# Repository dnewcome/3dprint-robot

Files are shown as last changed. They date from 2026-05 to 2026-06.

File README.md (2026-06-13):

# 3D-Printed Cycloidal Robot Arm

A 3D-printable cycloidal robot arm, designed for **low backlash**, **commodity
parts** (NEMA17, 608 bearings, magnets), and **fast iteration** on a home
printer. Two design tracks live here:

- **Integrated-actuator arm (current direction).** A **5-DOF** arm built from
  printed **sections** that fuse directly to off-the-shelf
  [Sweep Dynamics](https://www.sweepdynamics.com) **20:1 Micro Cycloidal**
  drives (a larger cycloidal at the base slew). Each section integrates one
  half of a joint at each end — the rotating cyclo **body** (upstream joint
  output) on one end, the **NEMA17 motor plate** (downstream motor mount) on
  the other — so the link *is* the actuator mount. See `arm_section.scad`.
- **From-scratch parametric joint (original track).** A **3-DOF** positioning
  trunk built around **one parametric cycloidal joint** (`cycloid_joint.scad`)
  used three times — no bought actuators. Kept as the ground-up alternative.

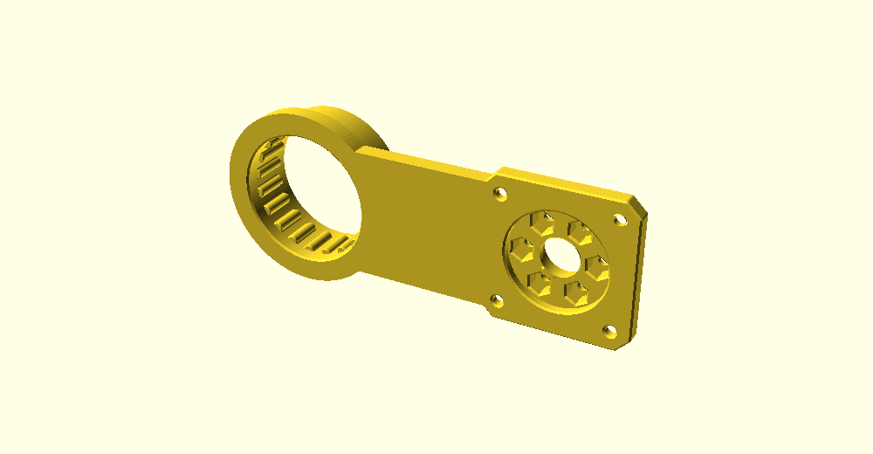
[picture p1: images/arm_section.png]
integrated arm section


**Full design rationale → [DESIGN.md](DESIGN.md).** This README is the map.

## Status
Active. **Current focus:** the integrated-actuator arm — the long arm section
is modeled and prints as one fused solid; the two 90° end sections (base→slew,
wrist→tool-roll) are next. No part is finalized for print yet.
**Toolchain:** the CAD is **[build123d](https://build123d.readthedocs.io)**
(Python + OCC) — it imports the vendor STEP files as exact solids, a better fit
for the fused-actuator parts than mesh import. The old OpenSCAD `.scad` sources
are **deprecated** and archived in [`legacy/`](legacy/README.md).

## Headline specs
| | |
|---|---|
| Near-term DOF | **3** (positioning trunk: J1 yaw + J2 shoulder + J3 elbow) |
| Future DOF | 5–6 via parked wrist / BLDC upgrades |
| Payload | 250 g |
| Reach | ~480 mm from shoulder |
| Print volume target | 250 mm cube |
| Joint drive | NEMA17 → 2:1 GT2 belt → cycloid (18:1) = **36:1** |
| Output bearing | large BB crossed-roller, **outboard of the gears** (J1's = the moment bearing) |
| Feedback | output-side absolute magnetic encoder per joint |

## Key decisions (the short version)
- **One cycloidal joint, three sizes** — build/tune once, reprint to scale.
- **Floating-roller cycloid** — nylon rollers, clearance sets backlash, SLA
  bearing surfaces for finish. No steel dowels required.
- **Bearing outboard of the gearset** (clevis-free stator/rotor cartridge) →
  carries the cantilever moment; **J1 = same cartridge vertical**, bearing sized up.
- **3 DOF is useful** — three joints position the tool point; bolt on a fixed
  gripper or manual wrist. Extra DOF is a deliberate later step, not v1.
- **Explorations parked, not deleted** — cable drive, wrist, BLDC, harmonic
  all live in [`parked/`](parked/) for when the trunk proves out.

## Repo map
**Build path (root)**
- `arm_section.py` — **the integrated-actuator links** (build123d, current
  direction). `python arm_section.py upper` fuses the Sweep micro-cyclo body +
  NEMA17 plate (exact STEP solids) into one printable section → `out/`.
- `arm_assembly.py` — **the assembled robot, the single source of truth.**
  Defines the kinematic chain once, derives joint frames from the part geometry,
  and generates the sim model (`sim/arm_trunk.urdf`), the meshes, and a CAD
  preview. Change a section length / motor here and it flows everywhere.
- `extract_vendor_steps.py` — pulls the two parts out of your purchased
  assembly STEP (run once before `arm_section.py` / `arm_assembly.py`).
- `vendor/` — the two Sweep Dynamics input parts + how to get the rest
  ([`vendor/README.md`](vendor/README.md)). Paid geometry — read [`NOTICE`](NOTICE).
- `encoder_joint_spec.md` — integrated output-side encoder.
- `DESIGN.md` — source of truth.
- [`CAD_NOTES.md`](CAD_NOTES.md) — build123d/OCP workflow + OCC gotchas
  (live preview, `make watch`, coincident-cut hangs, null-triangulation healing).
- [`LAB_NOTEBOOK.md`](LAB_NOTEBOOK.md) — running log of process variables
  (filament, color, print orientation, fits) + measured hardware anchors.
- [`legacy/`](legacy/README.md) — **deprecated** OpenSCAD `.scad` sources
  (`arm_section`, plus the from-scratch `cycloid_joint`/`arm_trunk` 3-DOF track).

**Simulation & analysis** → [`sim/`](sim/README.md) — MuJoCo model + tools to
pose it, size the motors (torque/reach/motor-catalog), budget backlash, watch it
hold/sag under gravity, and run a closed-loop reach controller (the digital-twin
foundation). Where the motor/reduction/backlash trade-offs were quantified.

**Parked explorations** → [`parked/`](parked/README.md) — cable/capstan drive,
wrist mechanisms, harmonic ring, BLDC motor options + integrated actuator,
and the now-merged joint-source files.

## Building the CAD
[build123d](https://build123d.readthedocs.io) (`pip install build123d`):
```bash
python extract_vendor_steps.py          # once: pull the 2 parts from your STEP
python arm_section.py upper             # -> out/upper.stl + out/upper.step
```
> Needs the **vendor geometry you purchase** from Sweep Dynamics (the assembly
> STEP) — see [`vendor/README.md`](vendor/README.md) and [`NOTICE`](NOTICE).
> Deprecated OpenSCAD versions render with `openscad` from [`legacy/`](legacy/README.md).

## Prototype plan
1. **One joint (J2)** — print the disc, pin ring, cam, flange + BB race;
   assemble with a NEMA17 + belt; measure backlash, repeatability, friction.
2. **J1 base** — same cartridge vertical; load-test the moment bearing.
3. **Trunk** — J1+J2+J3 + links; verify reach, stiffness, repeatability.
4. Then revisit a wrist (from `parked/`) for 5–6 DOF.

## References
- Cable-transmission arms (Barrett WAM, UC Berkeley Blue) — remote-cable inspiration.
- [Mishin Machine](https://youtube.com/@MishinMachine) — printed cable/wave-gear robotics.
- [Morse Dynamics](https://instagram.com/morsedynamics) — related printed robotics / drivetrains.
- [Skyentific](https://youtube.com/@Skyentific) — printed BLDC + cycloidal joint actuators.

## License & attribution
This project's own work (CAD source, simulation, docs) is **MIT** licensed
([`LICENSE`](LICENSE)). It is **not** affiliated with Sweep Dynamics. The two
bundled actuator meshes under `vendor/` are Sweep Dynamics' paid geometry,
included as derivative-design input with attribution — see [`NOTICE`](NOTICE).
Buy the actuators at [sweepdynamics.com](https://www.sweepdynamics.com).

---
*Developed iteratively; see DESIGN.md for the full reasoning and the parked alternatives.*

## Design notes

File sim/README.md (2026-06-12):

# Arm Simulation & Analysis Suite

A MuJoCo model of the arm plus a set of small, focused tools to **pose it, size
the motors, budget backlash, watch it behave under gravity, and close a control
loop** — built up as a learning/validation layer before anything is printed.

Everything here is plain Python + [MuJoCo](https://mujoco.readthedocs.io)
(`pip install mujoco`). Each script has its assumptions as editable constants at
the top — change a number, re-run, see the effect.

```
pip install mujoco
python sim/view.py          # pose it (kinematic)
python sim/gravity.py       # watch it hold/sag under gravity
python sim/sizing.py        # torque / reach / motor catalog
python sim/backlash.py      # backlash -> tool-tip error budget
python sim/twin_demo.py     # closed-loop reach-to-target (digital twin)
python sim/twin_demo.py fidelity   # measure sim-vs-"real" fidelity
python sim/gcode.py         # exact-path mode: draw a G-code shape
python sim/plan.py          # autonomy mode: collision-free pick around an obstacle
```

> **Display note:** MuJoCo's bundled GLFW here is Wayland-only, and its in-window
> UI sliders don't take mouse drags under native Wayland. The viewers therefore
> also accept **keyboard** control (`Q/A W/S E/D R/F T/G`, `X`=reset). Camera
> orbit/zoom with the mouse works fine.

---

## The model

`arm_trunk.urdf` is **GENERATED** — it is not hand-authored. The single source
of truth for the assembled robot is **`../arm_assembly.py`** (build123d): it
defines the kinematic chain once and derives each joint frame from the part
geometry, then emits the URDF + the section meshes + a CAD preview. Edit the
assembly, not the URDF.

The arm: **5-DOF** — J1 base slew, J2 shoulder, J3 elbow, J4 wrist pitch, J5 tool
roll. Every joint is the **20:1 Micro Cycloidal** except the base slew. The
upper-arm + forearm links **are the real printed sections** (`arm_section.py`):
each integrates the rotating cyclo housing (upstream output) at one end and the
NEMA17 motor plate (downstream mount) at the other — the section mesh *is* the
link. Base (slew→shoulder) and wrist (pitch→tool-roll) are 90° sections not yet
designed → simple stand-in geometry. Link masses/COM are computed from the part
geometry, so the analysis scripts read them straight from the model.

- **Regenerate** the model + meshes (needs build123d + your purchased STEP — the
  meshes embed Sweep Dynamics' paid geometry and are `.gitignore`d):
  `python extract_vendor_steps.py && python arm_assembly.py`. See
  [`../NOTICE`](../NOTICE).
- **Transmissions**: the URDF carries ROS `<transmission>` blocks recording each
  joint's reduction (20:1). `ros2_control` reads these; MuJoCo ignores them and
  the sim scripts inject their own actuators (see "Gotchas").

---

## The tools

### `view.py` — kinematic poser
Drag the joints (sliders or keys); the arm follows exactly, no gravity. Best for
checking reach, workspace, and self-clearance. Prints live tip position + radial
reach.

### `sweep.py` — animated workspace
Hands-free: sweeps the joints through a choreographed motion so you can see the
envelope. `--pose q1 q2 q3 …` holds a static pose.

### `gravity.py` — dynamics: hold or sag
Real physics. Gravity on, realistic link masses, and each joint is a position
servo whose force is **clamped to the actuator's real output torque**. So if a
pose needs more torque than the motor can make, the joint visibly sags. The
console prints per-joint torque and flags any joint over its **continuous
(thermal)** limit (`!`) — it can hold there briefly but it's cooking the motor.
Also models **friction / non-backdrivability** (`frictionloss`), so reaction
torques don't back-drive the joints like free pivots.

### `sizing.py` — torque, reach, motor catalog
A lumped-mass model + MuJoCo **inverse dynamics**: how much holding torque each
joint needs at worst case (arm horizontal, extended, with payload), vs what a
motor-on-cycloidal can deliver. The `MOTORS` catalog ranks bare steppers, geared
steppers, gimbal/pancake BLDCs — each at 20:1 vs 36:1 — by the longest members
they can hold continuously.

### `backlash.py` — backlash → tool-tip error
Per-joint backlash spec (`BACKLASH_DEG`) → worst-case slop at the tool tip, using
the translational Jacobian as each joint's lever arm. Shows which joints' lash
matters most and compares drive types.

### `robot.py` / `control.py` / `twin_demo.py` — the digital-twin foundation
- `robot.py` — **`RobotInterface`**, the one abstraction both sim and hardware
  implement (positions in, targets out). `SimRobot` wraps the MuJoCo model;
  `RealRobot` is a stub to wire to your encoders + drivers.
- `control.py` — a model-based **closed-loop IK** controller (damped least
  squares, integral feedback on the measured tip, anti-windup).
- `twin_demo.py` — drives the tool tip to a sequence of XYZ targets through the
  interface (`reach_demo`), and measures **fidelity** (`fidelity` arg) by
  replaying identical commands on a "truth" model and a mismatched "twin" and
  comparing tip paths.

### The two task modes
- `gcode.py` — **exact-path mode** (drawing / adhesive / paint): parse G-code
  (`G0/G1 X Y Z F`), map it onto a work plane in the robot's reach, and stream it
  through the controller so the tool tip traces the path (~0.7 mm). `--check`
  reports drawing-line accuracy; pass a `.gcode` file to run your own toolpath.
- `plan.py` — **autonomy mode** ("pick it up, don't collide"): give a grasp
  pose; an RRT-Connect planner finds a **collision-free joint path** (world
  obstacles + self-collision, checked in MuJoCo) and the arm executes it. Object
  poses in `OBJECTS` are the seam a perception module (webcam → pose) or an LLM
  ("pick the red block") would set. Key modeling point: the gripper is allowed to
  contact the object it's grasping; everything else must avoid everything.

---

## What the analysis found (the design conclusions)

These came out of `sizing.py` / `backlash.py` / `gravity.py` and drive the build:

1. **The shoulder is the binding joint, and reduction is the dominant lever.**
   At 20:1, almost no motor holds the arm extended *continuously*; going to 36:1
   (a belt pre-stage) roughly doubles the member length. Reduction beats motor
   upgrades for reach.
2. **Wrist-motor mass hurts twice** — its own weight loads the shoulder. Keep the
   wrist motors as light as possible; the tip-mass lever dwarfs the 250 g payload.
3. **Don't buy a geared motor — the metal planetary gearbox is the ~300 g.** A
   geared NEMA14 is 411 g, geared NEMA11 is 349 g; the gearbox dominates. Build
   the reduction in your **printed cycloidal** (light, ~0 backlash) and keep the
   motor bare.
4. **"Pancake" only helps as a BLDC outrunner.** Stepper torque ∝ stack *length*,
   so a flat stepper is just weaker (same torque/gram). BLDC outrunner torque ∝
   *radius²*, so a flat-and-wide pancake outrunner is genuinely torque-dense.
   Pancake BLDC 8108 @36:1 → ~0.62 m reach vs NEMA17's ~0.48 m. Cost: FOC +
   encoder per joint.
5. **Backlash budget: the base joints dominate.** At 0.2°/joint, J1/J2 (~470 mm
   lever) contribute ~1.6 mm of tip slop each; the tool-roll joint contributes ~0
   (tip on its axis). Spend tight tolerances on the base. Cycloidal (0.1–0.2°) →
   2–5 mm tip slop; a planetary geared stepper (1°) → ~24 mm. Hard number for
   "why cycloidal."

---

## Concepts (the things worth knowing)

- **Inverse dynamics** — given a pose (and zero acceleration), solve for the
  joint torques needed to hold it. How `sizing.py` and `gravity.py` get torques.
- **Jacobian** — the matrix mapping joint speeds to tip motion. Its column for a
  joint is also that joint's *lever arm to the tip* — used for both IK and the
  backlash budget.
- **Damped least squares IK** — invert the Jacobian to turn a desired tip move
  into joint moves, with a damping term for stability near singularities.
- **Three distinct "give" effects** (don't conflate them):
  - *Inertial coupling* — moving one link reacts a torque on the parent (load- &
    speed-dependent). Real, in the sim.
  - *Compliance* — elastic flex under load (modeled by servo stiffness `KP`).
  - *Friction / non-backdrivability* — the geartrain resists being back-driven
    (modeled by `frictionloss`). A high-reduction cyclo+stepper barely
    back-drives.
  - *Backlash* — a fixed dead-band, **load-independent** (so *not* the twitch you
    see when snapping a joint). `backlash.py` budgets it; it isn't in the dynamic
    sim yet.
- **Continuous vs holding torque** — a stepper holds near its full holding torque
  briefly, but only ~60% continuously before it overheats. The continuous number
  is what sizes a pose-holding arm.
- **FOC** (field-oriented control) — the closed-loop current control a BLDC needs
  to act like a servo; pairs with an encoder per joint.
- **Gymnasium** — just a standard *interface* (`reset()`/`step(action)`) so RL
  libraries can talk to any environment. Optional; only needed if you do RL.
- **Digital twin / fidelity** — run identical commands on sim and real arm,
  compare logged positions; tune the sim's params (friction, mass, stiffness) to
  minimize the difference (*system identification*). That difference is your
  fidelity number.

---

## Architecture: where the "brain" goes

Keep MuJoCo **dumb** — it only steps physics and reports state. Everything smart
lives above `RobotInterface`, which both `SimRobot` and (later) `RealRobot`
implement, so the same control/AI code runs against sim or hardware:

- **Classical IK + trajectory control** first — deterministic, debuggable (this
  is `control.py`). Good enough for positioning/pick-place.
- **LLM/VLM as a planner** on top — turns goals/language into target poses for
  the classical executor. (Doesn't run the fast loop.)
- **RL** only for genuinely hard skills (contact-rich, dynamic, learned
  compliance). Overkill for basic operation.
- **Transport**: in-process Python to start; add RPC (ZMQ/gRPC) or **ROS 2**
  (`mujoco_ros2_control` reads the transmissions) when you need cross-process or
  the real hardware.

---

## Gotchas / caveats

- **MuJoCo ignores URDF `<transmission>` and `<gazebo>` tags** — it has no
  actuators from the URDF (`nu=0`). The sim scripts add position-servo actuators
  via `MjSpec`. The transmissions are there for `ros2_control` / documentation.
- **Servo gains must scale with joint inertia.** A uniform stiff gain explodes on
  the near-zero-inertia wrist-roll joint (`KV·dt/I` blows past the explicit-
  integration limit). `gravity.py` scales per-joint gains to a common bandwidth
  and uses the implicit integrator.
- **Numbers are estimates.** Motor torques, efficiencies (0.70), masses,
  frictions are editable placeholders. They get *real* when you weigh printed
  parts and read motor datasheets — or, best, when you measure fidelity against
  the built arm.
- **What's modeled:** rigid-body dynamics, gravity, force-limited servos,
  joint friction/non-backdrivability, kinematic backlash budget.
  **Not yet:** dynamic backlash dead-band, gear/structural elasticity, thermal
  models, sensor noise.

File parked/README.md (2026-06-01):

# Parked explorations

These files are **not part of the current build path.** The near-term build
target is the 3-DOF cycloid trunk at the repo root (`cycloid_joint.scad` +
`arm_trunk.scad`). Everything here was option-generation that's been
superseded or deferred — kept for reference and likely future use.

See the root `DESIGN.md` for the full reasoning behind each.

## What's here

**Joint sources — merged into the root `cycloid_joint.scad`:**
- `cycloidal_disc.scad` — original validated cycloid profile math + pin ring.
- `joint_module.scad` / `_spec.md` — double-eccentric cam + output flange.
- `coaxial_joint.scad` / `_spec.md` — clevis-free stator/rotor cartridge
  (bearing outboard of the gears). The architecture the canonical joint uses.
- `belt_stage.scad`, `arm_link.scad` / `_spec.md` — belt pre-stage + link.
- `base.scad` / `.png` — superseded internal-ring (4:1) J1 base. J1 is now
  the cycloid cartridge stood vertical instead.

**Cable / capstan drive** (zero-backlash remote-tendon path; future experiment):
- `capstan.scad`, `capstan_drive.scad`, `capstan_spec.md`
- `capstan_teststand.scad` / `_spec.md` — remote-capstan test rig.
- `actuator_layout_spec.md` — distributed local-motor placement.

**Wrist** (for extending the trunk to 5–6 DOF later):
- `cable_wrist.scad` / `_spec.md` — pure-cable differential.
- `wrist_differential.scad` — bevel differential.
- `wrist_decision.md` — wrist mechanism trade study.

**Harmonic** (alternative reducer):
- `harmonic_ring.scad`, `harmonic_drive_spec.md` — flat strain-wave.

**BLDC** (motor upgrade path):
- `bldc_2204.scad` / `.png` — 2204-class outrunner fit model.
- `bldc_options.md` — KV-market breakdown + candidate comparison.
- `integrated_actuator.scad` / `.png` — frameless-motor-in-reducer concept.

**Earlier assemblies** (superseded by `arm_trunk.scad`):
- `arm_v1.scad` / `.png` — 5-DOF cycloid+bevel-wrist assembly.
- `arm_assembly.scad` / `.png`, `whole_arm.scad` — cable-architecture viz.
- `turntable.scad` / `_spec.md` — base layout.

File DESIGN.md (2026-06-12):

# 3D-Printed Cycloidal Robot Arm — Design

**Status:** pared down to a buildable near-term target — a **3-DOF cycloid
trunk** (J1 base + J2 shoulder + J3 elbow), all the *same* parametric joint
cartridge at three sizes. The earlier cable-driven / wrist / BLDC work is
kept as **parked exploration** under `parked/` (see §"Parked explorations").
This file is the source of truth; per-subsystem detail in `*_spec.md`.

> **CAD toolchain (2026-06):** the build CAD is now **build123d** (`arm_section.py`);
> the OpenSCAD `.scad` sources are deprecated to `legacy/`. The active build is the
> **integrated-actuator arm** (Sweep micro-cyclo fused into printed sections) — see
> the README. Much of §§1–13 below describes the from-scratch parametric-joint
> track and predates that pivot; §0.5 has the current actuator findings.

---

## 0. BUILD TARGET (current scope)
- **3-DOF cycloid trunk:** J1 (base yaw, vertical) + J2 (shoulder) + J3
  (elbow). Three joints position the tool **point** in space; a fixed
  gripper or manual wrist bolts to the forearm flange.
- **One joint design, three instances.** `cycloid_joint.scad` is the single
  parametric cartridge; J1/J2/J3 are presets (`cfg("J1"/"J2"/"J3")`).
  Assembly: `arm_trunk.scad`.
- **J1 base decision:** J1 is just the cartridge stood **vertical**; its
  output bearing, **sized up**, *is* the moment bearing (carries the whole
  arm's tipping load). No separate base mechanism.
- **Drive (every joint):** NEMA17 → 2:1 GT2 belt → double-eccentric cam →
  twin cycloid discs (180° = balanced) → 6 output pins → output flange on a
  big BB crossed-roller bearing. **Net 36:1** (18:1 cyclo × 2:1 belt).
- **Backlash strategy:** floating-roller cycloid (nylon rollers, clearance
  sets backlash, SLA bearing surfaces) + output-side magnetic encoder.
- **Future (parked):** wrist (pitch/yaw/roll) and/or BLDC integrated
  actuators extend this to 5–6 DOF *after* the trunk proves out.

## 0.5 Actuator findings from simulation (current — supersedes §10)
A full MuJoCo sim + analysis suite now lives in [`sim/`](sim/README.md). It
quantified the actuator trade-offs below; **re-run `sim/sizing.py` whenever you
change a motor/reduction** (edit the `MOTORS` catalog + masses, read off reach).
These supersede the cable-era numbers in §10.

**Torque budget (the binding facts):**
- The **shoulder (J2) is the binding joint** — it holds everything beyond it at
  full horizontal extension. Worst case for the current 5-DOF arm ≈ **5.25 N·m**.
- A NEMA17 (~0.44 N·m hold) × 20:1 × ~0.7 eff = **~6.2 N·m peak / ~3.7 N·m
  continuous** (steppers only sustain ~60% of holding before overheating). So at
  **20:1 the current geometry holds full extension only at near-stall** (cooking
  the motor). The 36:1 belt pre-stage in §0 is what gives real margin.
- **Reduction is the dominant lever for reach** — 20→36:1 roughly *doubles* the
  member length you can hold continuously; it beats motor upgrades.
- **Wrist-motor mass hurts twice** — a heavy motor at the tip both is dead weight
  *and* loads the shoulder. Keep wrist actuators as light as possible; the tip
  lever dwarfs the 250 g payload.

**Motor selection (what the catalog showed):**
- **Don't buy a geared motor.** The metal planetary gearbox is the ~250–300 g
  (geared NEMA14 = 411 g, geared NEMA11 = 349 g) — the gearbox dominates, not
  the frame. **Build the reduction in the printed cycloidal** (light, ~0
  backlash) and keep the motor **bare**.
- **"Pancake" only helps as a BLDC outrunner.** Stepper torque ∝ stack *length*,
  so a pancake stepper is just weaker (same torque/gram). BLDC outrunner torque ∝
  *radius²*, so a flat-and-wide pancake outrunner is genuinely torque-dense. Best
  case found: **pancake BLDC 8108 @36:1 → ~0.62 m reach** vs NEMA17's ~0.48 m.
  Cost: FOC driver + encoder per joint, and worse static-hold (current→heat at
  stall) — cuts against the "complexity out of tuning" value.
- Recommended pattern: **torque-dense motor at shoulder/elbow + lightest motor at
  the wrist**, all on the printed cycloidal. Never the same heavy motor everywhere.

**Backlash budget (`sim/backlash.py`):** tip slop = Σ(joint backlash × lever-arm
to tip). **The base joints (J1/J2) dominate** (~470 mm lever → ~1.6 mm each at
0.2°); the tool-roll joint contributes ~0. Spend tight tolerances on the base.
Cycloidal (0.1–0.2°) → **2–5 mm** tip slop; a planetary geared stepper (1°) →
**~24 mm** — the hard number for "why cycloidal, not a gearbox."

**Sim caveats:** efficiency 0.70, motor torques, masses, and frictions are
editable estimates — they get *real* when you weigh printed parts, read motor
datasheets, and measure fidelity against the built arm (the `sim/twin_demo.py`
fidelity path). The sim is confidence-validated for sizing; treat the absolute
numbers as guidance until tuned against hardware.

## 1. Goals & constraints
- **Near-term: 3-DOF** positioning trunk (above). 5–6 DOF is the parked
  upgrade path (wrist), not the current build.
- **Payload:** 250 g at the tool.
- **Print volume:** 250 mm cube. One-piece links ≤ ~180 mm; larger split
  and bolt.
- **Reach:** ~480 mm from the shoulder (a1=a2≈210 mm + tool).
- **Low backlash** is the governing value — drove the cycloid choice
  (floating rollers, output-side encoders, bearing outboard of the gears).
- **Commonly available actuators:** NEMA17 steppers, open-loop to start;
  no servo drives required.
- **Cost/printability** over precision-machined parts.

## 2. Architecture at a glance
```
 table ─ pedestal ─ J1 yaw (vertical, big moment bearing) ─ mast
   ─ J2 shoulder ─ upper arm ─ J3 elbow ─ forearm ─ [tool flange]
```
- **Drive:** identical cycloidal cartridge at every joint (`cycloid_joint
  .scad`), 36:1, clevis-free stator/rotor with the crossed-roller bearing
  **outboard of the gears** so it carries the cantilever moment.
- **Motors:** NEMA17, coaxial-ish via a 2:1 belt pre-stage (which also puts
  the cam on its own supported shaft and lets the motor be repositioned).
- **Every joint:** large BB crossed-roller output bearing + output-side
  absolute magnetic encoder + open center bore for cables/encoder magnet.

## Design philosophy — complexity arbitrage
Spend the thing 3D printing makes free (arbitrary geometric complexity) to
buy down what's actually expensive: precision-machined/specialty parts,
money, and lead time. Prefer **clever printed shapes + commodity hardware**
(NEMA17, 608 bearings, steel dowels, nylon spacers, Dyneema, magnets) over
simple shapes that need bought precision. Higher *conceptual* complexity is
an acceptable price for *part availability* and fast iteration.

**The refinement that protects "iterate easily":** 3DP makes *fabrication*
complexity free — it does NOT make *assembly/tuning/debug* complexity free.
The real limit on iteration speed is part count, tolerances, and things you
must calibrate (cable tension, backlash, coupling), not print cost. So the
rule isn't "minimize complexity" — it's **push complexity into the printed
geometry, keep it out of the assembly/tuning loop: complex to print, simple
to build and tune.**

Tactics to keep the iteration loop cheap:
- **Modular swappable joints** — iterate by reprinting one part, not the arm.
- **Reuse hardware, reprint plastic** — a revision costs filament + an hour,
  never new bought parts.
- **Parametric files** (`capstan.scad` etc.) — a change is a number, not a remodel.
- **Engineer the tuning out** — constant-force tensioner (no re-tensioning),
  output encoders (calibrate coupling instead of building it out).

## 3. Governing design principles
1. **Cable, not printed gears, for low backlash.** Cables are always in
   tension → no lash; printed strain-wave/cycloidal/bevel all carry lash.
2. **Output-side absolute encoder on every joint.** True joint angle,
   immune to upstream slop; enables homing without limit switches and
   makes any residual coupling calibratable.
3. **The output moment bearing is the real bottleneck**, not the
   reduction. Size it big, concentric, outboard. Validate it first.
4. **Mount each motor just distal to its joint's predecessor** → tendon
   stays in one moving frame → no coupling matrix.
5. **Prove one joint before replicating.** De-risk on the bench.

## 4. Joint drive — Dyneema capstan
- **Reduction (bends J2/J3):** 2-stage capstan, 6:1 × 6:1 = **36:1**.
  Drum r=10 mm, pulley/sector R=60 mm.
- **Cord:** **Dyneema DM20 (UHMWPE)**, anchored both ends (terminated
  capstan = zero slip). Bends to ~5× dia.
- **Cord sizing by CREEP, not strength:** keep pretension + peak load
  < ~25% MBL → target MBL ≥ ~1050 N for J2. Use SK78/SK99, pre-stretch.
- **Constant-force spring tensioner per cord** — non-negotiable: takes up
  creep automatically and preserves pretension (a fixed turnbuckle goes
  slack and reintroduces lash).
- **Terminations:** splice (Brummel/locked bury) or anchored wraps + clamp.
  **No knots** (slip, −50% strength). Radius all groove/anchor edges.
- **Helical groove, pitch = cord dia**, on every drum (prevents wrap
  climbing).
- Detail: `capstan_spec.md`, `capstan_drive.scad`.

## 5. Output bearing & encoder (shared by all joints)
- **Bearing:** large crossed-roller — printed **airsoft-BB race
  (~90–104 mm)** or a bought thin-section (6810, 50×65×7). Single bearing
  reacts the full cantilever moment; bigger + outboard = stiffer.
  **This is Proto 1 — validate before anything else.**
- **Encoder:** diametric 6×2.5 mm magnet on the output + magnetic IC.
  **AS5600** (12-bit I²C, $3) for prototyping → **MT6701** (14-bit SSI)
  for production. Same magnet/mount, drop-in upgrade.
  - Keep steel (bearing, fasteners) ≥ ~8 mm from the magnet.
  - AS5600 address fixed (0x36) → one per bus; use a TCA9548A mux or one
    MCU per joint on a shared bus.
- Detail: `encoder_joint_spec.md`.

## 6. Actuator layout — distributed local cable drive
Each joint's motor on the link just distal to the upstream joint → no
tendon crosses a joint → no coupling. Supersedes the all-on-turntable
cable-trunk idea for v1.

| Motor | Mounted on | Drives |
|---|---|---|
| J1 | ground (fixed, zero inertia cost) | base yaw → turntable |
| J2 | turntable | shoulder |
| J3 | upper-arm proximal | elbow |
| wrist (2–3) | forearm proximal (just after elbow) | wrist DOF |
| gripper | forearm (Bowden) | gripper |

- Mass stays near each carrying joint's axis (low moment); J2 lands
  ~5–7 N·m worst case — within budget.
- **Electrical crosses J1**: slip ring (many conductors) or service loop
  if J1 ≤ ±180°.
- **Upgrade path:** to chase distal mass later, move motors proximal and
  re-introduce through-joint routing (concentric idler trunk + coupling
  matrix, per `turntable_spec.md`). Joints/tendons unchanged.
- Detail: `actuator_layout_spec.md`, `turntable_spec.md`.

## 7. Wrist — pure-cable differential (zero backlash)
Trade study (`wrist_decision.md`) rejected every geared/exotic option for
backlash or buildability; **landed on an all-cable wrist.**

- **Cable differential (2 cords) → pitch + yaw** (no gears → no gear lash).
- **3rd cord pair over a pitch-axis-concentric idler → roll** (the
  zero-backlash way to carry rotation across the bend — a tendon, not a
  U-joint/shaft). = full 3-DOF, zero lash, all forearm-driven (WAM-style).
- Each cord pair routes down the forearm centerline over the pitch-axis
  idler; the third axis is **incremental** (one more cord pair + idler +
  one calibratable coupling term).
- **Rejected options (do not revisit):**
  - **ABENICS cross-spherical:** each drive module is ~2-DOF (gears must
    tilt to stay meshed); no off-the-shelf 2-DOF drive → not DIY-buildable.
  - **Roller-driven sphere:** slip + 3-DOF orientation sensing.
  - **Agile Eye (spherical parallel):** limited tilt + precise curved
    links.
  - **Bevel differential:** gear backlash at the tool.
  - **U-joint roll shaft through the bevel:** stacks bevel + Cardan lash —
    betrays the zero-backlash premise.
- Detail: `wrist_decision.md`, `cable_wrist_spec.md`, `wrist_differential.scad`
  (note: the bevel `.scad` is now a rejected reference).

## 8. Gripper
- **Single-acting Bowden tendon + spring return:** one cord pulls to close,
  spring opens. Grip force = motor current.
- Holding 250 g needs ~10–20 N grip → ~30 N cord tension → trivial (0.5 mm
  Dyneema). Bowden lets the motor sit back; sheath friction adds
  hysteresis (fine for grasping, not precise force control).

## 9. Geometry & reach
| Param | Value |
|---|---|
| Base column / shoulder height | ~118–150 mm |
| Upper arm (J2→J3) `a1` | 200 mm |
| Forearm (J3→wrist) `a2` | 200 mm |
| Wrist→tool `a3` | 90 mm |
| Reach from shoulder | ~490 mm |
| Max tip height | ~610 mm |
- Visualize/pose: `arm_assembly.scad` (→ `arm_assembly.png`),
  `whole_arm.scad`.

## 10. Torque / sizing budget — SUPERSEDED by §0.5 (cable-era numbers)
*(These were for the parked Dyneema-capstan drive. For the cycloidal build, use
§0.5 and `sim/sizing.py`.)*
- **NEMA17 throughout** (run ≤ ~50% holding open-loop). No NEMA23 needed.
- Bend joints at 36:1: ~24 N·m available vs ~11 N·m worst-case demand.
- **Capstan torque ceiling** = working tension × sector radius ≈ **16 N·m**
  at R=60 mm (bump J2 sector to 80 mm for margin).
- **Cable is inherently protected:** NEMA17 stall × ratio can't exceed the
  cord's working load → set stepper run-current as an electronic torque
  limit.
- Wrist & gripper loads are < ~0.5 N·m — trivial.
- **Counterbalancing: deliberately omitted.** The arm is light enough that
  gravity comp isn't needed. A J2 spring/gas strut is a known bolt-on
  (lowers holding torque + cable pretension) if it's ever wanted — no
  architecture change to add it.

## 11. Control
- Open-loop steppers + output-side absolute encoders for homing and
  position readout (closed loop later if wanted).
- Distributed motor layout → **no inter-joint coupling** to compensate in
  v1. The only coupling is the wrist's 3rd-axis cord crossing the pitch
  axis → one calibratable term (move the joint, log the encoders).
- One MCU per joint (or per cluster) on a shared bus is the cleanest given
  the AS5600 single-address constraint.

## 12. Open decisions
1. **Actuator selection (active iteration).** Per §0.5: reduction in the printed
   cycloidal (not a metal gearbox), motor kept bare. Open: stepper vs BLDC at the
   load joints (NEMA17+cyclo is simple; pancake-BLDC+cyclo is lighter/longer-reach
   but needs FOC+encoder ×N); the lightest wrist motor (NEMA8/11 vs small BLDC);
   and the load-joint reduction (36:1 belt pre-stage vs a larger single-stage
   cyclo). Re-run `sim/sizing.py` as candidates change.
2. **6-DOF vs 5-DOF / wrist mechanism** (parked until the trunk proves out).
3. **Single vs per-cluster MCU / bus topology.**
4. **Output bearing:** printed BB race vs bought thin-section (decide on
   Proto 1 results).

## 13. Prototype / de-risk plan
1. **Proto 1 — output bearing coupon.** Printed BB crossed-roller race;
   hang 250 g at 450 mm, measure wobble (<0.5 mm). Decides BB vs bought.
2. **Proto 2 — one capstan joint.** Motor + 2-stage capstan + Dyneema +
   sector on the Proto-1 bearing + AS5600. Measure **backlash (~0 is the
   whole point), repeatability, cable creep/tension hold** over cycling.
3. **Proto 3 — pure-cable wrist (2-DOF first).** Cable differential
   pitch+yaw on the bench; validate zero backlash and routing/fleet angle
   before adding the 3rd cord.
4. Then replicate + integrate the full arm.

## v1 build configuration — SUPERSEDED (see §0 BUILD TARGET)
The earlier v1 config (internal-ring J1 + cycloid J2 + a J3 capstan/cycloid
**fork** + bevel-differential wrist, 5-DOF) has been **pared down**. The
resolved decisions now live in §0:
- **DOF:** 6→**3-DOF trunk** for the near-term build; wrist parked.
- **J3 fork → resolved:** elbow is **cycloid** (same cartridge), not capstan.
  The Dyneema rig moves to `parked/` as a separate future experiment.
- **J1 → resolved:** **cycloid** cartridge stood vertical (not the
  internal-ring drive); its sized-up output bearing is the moment bearing.
- **All three joints share ONE cartridge** (`cycloid_joint.scad`) — the
  modularity the philosophy called for, now literal.

## 14. File index
**Build path (top level):**
- `DESIGN.md` — this file (source of truth).
- `cycloid_joint.scad`/`.png` — **THE joint.** One parametric cycloidal
  cartridge; J1/J2/J3 are presets. Consolidates the old cycloidal_disc +
  joint_module + coaxial_joint + base files.
- `arm_trunk.scad`/`.png` — **the build-target assembly** (3-DOF trunk).
- `encoder_joint_spec.md` — integrated output-side encoder.

**Parked explorations (`parked/`):** kept for reference, OUT of the build
path — see §"Parked explorations" / `parked/README.md`. Includes the
cable/capstan drive, pure-cable & bevel wrists, harmonic ring, BLDC motor
options + integrated actuator, the superseded internal-ring base, the
earlier multi-DOF assemblies (`arm_v1`, `arm_assembly`, `whole_arm`), and
the now-merged `cycloidal_disc`/`joint_module`/`coaxial_joint` sources.

## 15. Candidate parts / references
- **Roll-joint reducer (OPTIONAL, post-capstan):** Mishin Machine's
  **rolling-element wave gear** (strain-wave/cycloidal hybrid with steel
  balls/rollers — printed profiles, steel does the wear/precision).
  Better printable reducer than the cycloidal/harmonic fallback; good
  candidate for **J1 (and optional J4/J6)** continuous-rotation joints
  where capstan's finite travel doesn't work. Parametric OnShape model +
  NEMA17 housing + generator available. NOT for the bend joints (those
  stay cable). Print + measure backlash before trusting it. Decision:
  deferred — **capstan drive is being prototyped first.**
  Channel: youtube.com/@MishinMachine (similar printed cable/gear robotics).
- **Morse Dynamics** (instagram.com/morsedynamics) — closely related
  printed robotics / actuator-drivetrain work; reference for joint, drive,
  and reducer techniques.
- **Skyentific** (youtube.com/@Skyentific) — printed **BLDC + cycloidal
  integrated robot-joint actuators** (frameless motor built into the
  reducer, FOC, dual encoders); closest existing work to the integrated-
  actuator idea below. Also covers inverted/decoupled cycloid topologies.

### Design idea (PARKED — not committed): pancake BLDC joint actuator
Replace the coaxial stepper with a low-profile **pancake BLDC** (~90 mm OD,
matching the cycloid ring) for a thin integrated actuator + backdrivable /
force-controllable motion. Key findings:
- **Don't look for an inrunner.** A 90 mm low-profile inrunner-with-shaft
  doesn't exist and is the wrong topology: torque ∝ rotor radius, so big
  pancakes put magnets at large radius = **outrunner or frameless**. An
  inrunner here = low torque + high Kv (wrong for a joint).
- **Two viable parts:**
  - *Gimbal outrunner* (T-Motor GB / iPower GBM / generic ~90 mm, low Kv,
    ~15–30 mm tall) — easiest, off-the-shelf. Mount the static core to the
    joint body, **bolt the eccentric cam to the rotating bell** (no shaft).
  - *Frameless BLDC kit* (rotor ring + stator ring) — build your own
    inrunner-style with a protruding shaft; max integration, more assembly.
- **Electronics:** needs FOC (ODrive / SimpleFOC / VESC) + commutation
  encoder — this is "building servo drives." Synergy: the planned magnetic
  encoder (AS5048/MT6701) **doubles as the FOC sensor**.
- **Still keep the cycloid reduction** — BLDC upgrades the motor, not the
  gearbox; and a low-ratio BLDC must draw current to hold a pose (heat) →
  meaningful reduction needed. BLDC **+ cycloid**, not direct-drive.
- **Don't load the motor's light bearings** with the eccentric — let the
  cycloid's own input bearing carry it; motor supplies torque only.
- **Sequencing:** design the joint cartridge **dual-use** (stepper+belt now
  / frameless BLDC stator bore later); prototype mechanics with cheap
  open-loop steppers first, swap to BLDC once compliance/smoothness is
  wanted. The 90 mm cycloid ring already matches a 90 mm motor → drop-in.
- **Status:** parked — adds electronics/tuning complexity (against
  "simple to build/tune"); revisit after the stepper+cable mechanics prove
  out. Capstan/stepper remains the committed path.

#### Sub-idea: small-frame BLDC + reduction as a NEMA-17 drop-in
Evaluating several off-the-shelf BLDC options (e.g. a 2204-class drone
outrunner, modeled in `bldc_2204.scad`, through to larger gimbal frames).
A small BLDC **+ reduction can stand in for a NEMA 17 at a fraction of the
mass** — the torque/speed numbers are easy; thermal-at-stall and control
are the real constraints.
- **Torque math (2204-1400KV example):** `Kt = 8.27/Kv ≈ 5.9 mN·m/A`.
  - 10 A burst → 59 mN·m → only **~7:1** to match a 0.4 N·m NEMA-17 hold.
  - 3 A sane-continuous → 18 mN·m → **~22:1** for 0.35 N·m output.
  - Our existing 4–36:1 reductions already cover this; ≥20:1 gives
    NEMA-17-class continuous torque and several × that on burst.
- **Speed is surplus:** ~15,000 rpm free-run on 3S → ~430 rpm output even
  at 36:1. You trade away speed to buy torque — exactly what's wanted.
- **Mass win:** 2204 ≈ **28 g** vs NEMA 17 ≈ **280 g**. Even with a printed
  cycloid stage, well under the stepper → big distal-link inertia drop
  (serves the "mass off the arm" goal). Good **wrist / gripper** candidate.
- **Catch 1 — holding against gravity is the BLDC weak spot:** ~zero detent
  torque, so holding a pose = servoing current at **zero rpm** = worst-case
  heat with no propwash. Fix with enough reduction (low holding current),
  a detent brake, or a self-locking-ish stage.
- **Catch 2 — commits to FOC:** ODrive / SimpleFOC + encoder. The planned
  output-side magnetic encoder **doubles as the commutation sensor**.
- **Catch 3 — 1400 KV is the wrong wind for a joint:** racing motors are
  wound for speed (need high current → stall heat) and their "continuous"
  rating assumes prop cooling we won't have. **Prefer a low-KV gimbal wind**
  (~100–200 KV, e.g. GB2208 / 4008-class) in the same frame: 7–14× the
  torque-per-amp, so holding current and heat drop hard. Same envelope /
  CAD, just rewound. **Spec gimbal-wound for any joint that holds load.**
- **Takeaway:** as a *frame*, a small BLDC is a viable drop-in for a distal
  joint at ≥20:1 with a derated thermal budget; as a *racing wind* it runs
  hot at stall. `bldc_2204.scad` is the fit/envelope model for trial fits.
- **Mishin techniques worth borrowing:**
  - *Belt pre-stage* — already used (2:1 GT2 into the reduction).
  - *Right-angle cycloid* — reduction + 90° axis turn in one unit; tucks a
    motor along a link to drive a perpendicular joint. Gear-path only
    (relevant if a bend joint ever goes geared).
  - *Through-bore / decoupled-center cycloid* — hollow joint center to
    route the dress-pack + downstream tendons ON the rotation axis. Useful
    regardless of drive type — carry into the joint housings.
  - His cycloidal cartridge ≈ our `cycloidal_disc.scad` (steel dowels,
    eccentric cam, output-pin disc) — validates the fallback joint design.

### Design idea: integrated BLDC-cycloidal actuator (one drive unit)
Build a **frameless BLDC into the cycloidal reducer** so motor + gearbox +
encoders are a single sealed unit — the big payoff of going BLDC. Model:
`integrated_actuator.scad` (concept cross-section). Prior art: commercial
Harmonic Drive **FHA** / Nabtesco **RV** / **CubeMars AK** & T-Motor joints;
DIY/printed: **Skyentific** (closest existing work — printed BLDC-cycloidal
robot-joint actuators).

- **Frameless motor = stator ring + rotor ring, no housing/bearings.** You
  supply the structure, so the magnetics build directly into the cycloid's
  members instead of bolting on a separate motor.
- **Member mapping:**
  - rotor magnet ring → **eccentric carrier** (input, motor speed)
  - stator ring → **fixed** to the housing (alongside the pin ring)
  - output disc/plate → rides the big **moment bearing** (slow output)
  - This makes the earlier **bell-as-eccentric** idea concrete: the rotor
    *is* the bell; its eccentric crank drives the disc.
- **Reduction** unchanged — still set by lobe count (`cycloidal_disc.scad`
  math). The motor fills volume the reducer already had → ~zero extra axial
  space beyond the magnet zone.
- **Four integration-specific challenges** (don't exist for a bolt-on motor):
  1. **Air gap must stay concentric, isolated from the eccentric.** Magnet
     ring spins truly concentric on a **main bearing**; only a separate
     eccentric crank on the rotor drives the disc. If disc load deflects the
     magnets into the stator → cogging / rub / dead motor. Main bearing
     (thin-section ball or printed BB race) takes the cycloid side-load so
     the magnets never see it.
  2. **Heat path.** Windings buried in plastic (an insulator) + stall-hold
     current = cooking risk. Bond stator to a **metal insert** tied to the
     housing, run **low-KV** (~2 A hold), add a winding **thermistor**.
     This is the constraint that most often bites printed integrated actuators.
  3. **Two encoders.** Rotor-back magnet (AS5048, FOC/commutation) + output
     magnet (MT6701, absolute joint angle). Both sensors on the **static**
     housing → no wires cross a rotating interface, no motor slip ring.
  4. **Balance.** Eccentric orbiting mass shakes — use **twin discs 180°
     out of phase** (also wanted for smoothness).
- **Two forks:**
  - *Outrunner vs inrunner frameless* — outrunner (magnets at large radius)
    = more torque but magnet-zone and pin-ring-zone stack **axially** (a bit
    taller); inrunner is flatter but lower torque density. → **outrunner**.
  - *Cycloidal vs harmonic* — frameless integrates even more naturally into
    **harmonic** (wave generator = rotor, gap concentric by construction =
    the FHA architecture), but needs a durable **printed flexspline**.
    Cycloidal is the print-robust choice; harmonic the elegant one.
- **Status:** concept — same parked rationale (electronics/tuning vs "simple
  to build/tune"). The unit unifies low-KV motor + bell-as-eccentric + output
  moment bearing + dual encoders into one part; revisit after stepper+cable
  mechanics prove out.

## Parked explorations (`parked/`)
Out of the current build path, kept as reference. The reasoning above (cable
drive, wrist, BLDC, complexity-arbitrage) still applies if/when these come
back. See `parked/README.md` for the full list. Grouped:
- **Joint sources now merged into `cycloid_joint.scad`:** `cycloidal_disc`,
  `joint_module*`, `coaxial_joint*`, `belt_stage`, `arm_link*`, `base*`.
- **Cable / capstan drive:** `capstan*`, `actuator_layout_spec` — the
  zero-backlash remote-tendon path; a future de-risking experiment.
- **Wrist:** `cable_wrist*`, `wrist_differential`, `wrist_decision` — the
  pitch/yaw/roll options for extending the trunk to 5–6 DOF.
- **Harmonic:** `harmonic_ring`, `harmonic_drive_spec` — flat strain-wave
  alternative reducer.
- **BLDC:** `bldc_2204`, `bldc_options`, `integrated_actuator` — motor
  options + the frameless-motor-in-reducer integrated-actuator concept.
- **Earlier assemblies:** `arm_v1`, `arm_assembly`, `whole_arm`,
  `turntable` — superseded by `arm_trunk.scad`.

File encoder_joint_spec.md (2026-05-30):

# Integrated joint encoder — spec (output-side, absolute)

Goal: true joint angle, fully built-in, no purchased rotary encoder.
A diametric magnet on the **output** shaft end + a magnetic-encoder IC
on a small PCB fixed to the **non-rotating** housing, ~1–2 mm away.

## Two-tier plan
| Tier | IC | Bits | Bus | Use |
|---|----|---|-----|-----|
| Prototype | **AS5600** | 12 (4096) | I²C @0x36 | dead simple, $3 breakout, great libraries |
| Production | **MT6701** | 14 (16384) | SSI/SPI or I²C | higher res + speed, same magnet |

Start with AS5600 on Proto 2; the magnet & mechanical mount are
identical, so swapping to MT6701 later is drop-in.

## Magnet (the part that matters most)
- **Diametrically magnetized** cylinder, **6 mm Ø × 2.5 mm**, N35+.
- Mounted **on the rotation axis**, on the very end of the output shaft.
- Air gap to IC face: **0.5–2 mm** (aim ~1.5 mm).
- Lateral centering: **±0.25 mm** — runout shows up directly as angle error.
- Holder must be **non-ferrous** (brass/alu/plastic). Keep steel screws,
  the output bearing, and the dowel pins **≥ ~8 mm away** or they skew
  the field. This is the #1 cause of bad readings — design the magnet
  boss to stick out past any steel.

## AS5600 (SOP-8) wiring — prototype
| Pin | Name | Connect |
|-----|---|---|
| 1 | VDD3V3 | 3.3 V (add 100 nF) |
| 2 | VDD5V  | 5 V if 5 V supply (internal LDO), else tie to VDD3V3 |
| 3 | OUT | leave NC (using I²C) |
| 4 | GND | GND |
| 5 | DIR | GND = one count direction (tie high to flip) |
| 6 | SCL | I²C clock (4.7 kΩ pull-up) |
| 7 | SDA | I²C data  (4.7 kΩ pull-up) |
| 8 | PGO | NC (factory-prog only) |

- I²C address is fixed **0x36** → only ONE AS5600 per bus. For 6 joints
  use an **I²C mux (TCA9548A)** or one MCU per joint on a CAN/serial bus.
- Read `RAW ANGLE` (0x0C/0x0D) for unfiltered absolute position.

## MT6701 — production
- 14-bit absolute, supports **SSI (3-wire: CSN/CLK/DO)**, I²C, ABZ, PWM.
- Prefer **SSI/SPI** for the arm: no address clash, daisy-chain-able,
  fast enough for closed-loop later.
- 3.3 V logic. Same 6×2.5 mm diametric magnet, same ~1.5 mm gap.
- Verify exact SOP-8 pin numbers against the MT6701QT datasheet before
  laying out the PCB (pinout differs from AS5600).

## Dual-encoder forward-compat
Add a second identical magnet boss on the **motor shaft** end of each
module (don't populate the IC yet). Output-side = absolute joint angle
for homing/accuracy; motor-side = commutation/anti-stall when you go
closed-loop. ~$2 of board + magnet now saves a redesign later.

## Homing bonus
Absolute output-side encoders mean **no limit switches**: power on and
every joint angle is already known. Store a one-time per-joint zero
offset in config.

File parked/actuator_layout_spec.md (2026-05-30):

# Actuator layout — distributed local cable drive (v1)

Supersedes the all-on-turntable cable-trunk plan (`turntable_spec.md`) for
v1. Core principle below eliminates inter-joint coupling.

## Principle: motor on the link just DISTAL to its joint's predecessor
Each joint's motor mounts on the proximal end of the link it drives, just
past the upstream joint. The tendon then stays entirely within ONE moving
frame and never crosses a joint → **no kinematic coupling, no concentric-
idler trunk, no coupling matrix.** Trade: more distal mass than all-at-
base, but each motor sits near its carrying joint's axis (low moment arm).

## Motor placement
| Motor | Mounted on | Drives | Tendon path |
|---|---|---|---|
| 0 | ground (fixed, no inertia) | J1 base yaw | direct/geared |
| 1 | turntable | J2 shoulder | short |
| 2 | upper-arm proximal (after J2) | J3 elbow | along upper arm |
| 3,4 | forearm proximal (after J3) | wrist differential | along forearm to wrist |
| (5) | forearm proximal (after J3) | **J4 forearm roll — OPTIONAL** | see DOF note |
| grip | forearm (Bowden) | gripper | Bowden sheath to tool |

## Mass / torque check
- J3 motor at upper-arm proximal: ~near J2 axis → negligible J2 moment.
- 2 (or 3) wrist motors at elbow (~200 mm from shoulder): ~1.1 N·m (2) or
  ~1.6 N·m (3) added to J2. Within budget; J2 lands ~5–7 N·m.
- No motor is out at the wrist → distal mass stays low, joints stay light.

## DOF decision (OPEN)
The 5-motor list above is **5-DOF** (J1,J2,J3 + wrist pitch/roll); it drops
**J4 forearm roll**.
- **5-DOF:** position + 2 orientations. Simpler, lighter — strong v1.
- **6-DOF:** add motor 5 (J4) at the forearm proximal with the wrist pair.
  Restores full dexterity; forearm carries 3 motors.
Both obey the placement principle. J4, if added, mounts BEFORE the wrist
diff — then the wrist-diff motors should ride the rolling forearm section
to avoid crossing J4 (or accept one forgiving linear J4 coupling term).

## Gripper
- **Single-acting Bowden + spring return:** one cord pulls to close, spring
  opens. Grip force = motor current.
- Motor sits back on the forearm; Bowden sheath routes the cord to the
  tool. Caveat: sheath friction adds hysteresis → fine for grasping, not
  for precise force control.

## Reduction per joint (local capstan)
- Tendons are short (one link), so single- or 2-stage capstan as needed.
- J2/J3: 2-stage ~36:1 (load joints). Wrist: lower ratio, low load.
- Output-side absolute encoder at each joint (no coupling to untangle now,
  but still wanted for homing + zero backlash readout).

## Upgrade path
To chase distal mass later: move motors further proximal and re-introduce
through-joint routing (concentric idlers + coupling matrix per
`turntable_spec.md`). Joints, sectors, and tendons are unchanged — only
routing and firmware. Defer until mass actually bites.

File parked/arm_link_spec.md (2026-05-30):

# Arm link / drive housing — structure, loads, printing

`arm_link.scad` = one printable arm segment: a **joint cup** that the
36:1 drive drops into, a **link tube**, and a **proximal face** that
bolts to the previous joint's output ring. Parametric on `link_len` so
the same model makes upper arm, forearm, etc.

## What the cup carries (load path)
```
 payload + arm weight
      │  (bending moment)
      ▼
 next link (YOKE) ── bolted to ── OUTPUT RING
      │
   6810 main output bearing  ←── THE stiffness bottleneck. Its seat in
      │                            the front lip must be round & snug.
 housing cup wall  ── hoop + bending ──►  link tube  ──►  prox face
                                                           │
                                              previous joint output ring
```
The gear torque reacts through the **integral pin ring** (dowels in the
cup wall) → the cup hoop. The bending moment reacts through the **6810
seat** → cup wall → tube. Keep these two paths stiff; everything else is
packaging.

## Key dimensions (derived, all parametric)
| Feature | Value | From |
|---|---|---|
| Housing OD at joint | ~98 mm | `2·(ring_R+Rr+ring_wall)+10` |
| Cup interior depth | 46 mm | disc stack + flange + bearing |
| Structural wall | 4 mm | `wall` (≥3 perimeters) |
| Output bearing seat | 65 mm (6810) | `out_brg_OD` |
| Back boss | twin 608, 18 mm apart | `in_brg_gap` |
| Motor pad offset | 30 mm | `C_nom` (belt center dist) |
| Link tube | 42 mm OD × `link_len` | per joint |

## Print strategy
- **Orient the cup with the joint axis VERTICAL.** Then the output-
  bearing seat, the pin-ring bores, and the 608 seats all print as round
  holes with no support inside them — bore roundness drives backlash.
- Print the **link tube** as part of the same body if `link_len` ≤ ~180 mm
  (fits the 250 mm bed on the diagonal); longer links → split and bolt at
  the prox face.
- **PETG or PA-CF**, 4 perimeters / ≥40% infill in the cup, gyroid in the
  tube. The cup is the loaded part; the tube mostly just needs to not
  twist.
- **Heat-set brass inserts** for every M3 (motor pad, prox face, encoder
  bridge). Don't tap plastic for fasteners that get reworked.

## Bearing seat fits
- **6810 seat (65 mm):** model at 65.0; PETG shrinks slightly → usually a
  light press. If loose, add a 0.1 mm shim or a smear of retaining
  compound. A loose output seat = a wobbly arm, so check this first.
- **608 seats (22 mm):** light press; the pair must be **coaxial** — print
  vertical so they share the same Z axis.
- **Pin-ring dowel holes:** `Rr+0.10` = press fit for 6 mm dowels.

## Encoder bridge & cabling
- The output center is **open by design**. A 2-leg `encoder_bridge()`
  bolts to the front lip and holds the AS5600/MT6701 PCB ~1.5 mm above
  the magnet glued to the output ring's center web.
- The same open bore is the **cable pass-through** — run motor + encoder
  wires of the *downstream* joints through the joint center near the
  rotation axis so they barely flex as the joint moves. Leave a service
  loop; don't pull them taut.
- Keep the steel output bearing and dowels ≥8 mm from the magnet (the
  open center naturally gives this clearance).

## To refine in real CAD (this .scad is the skeleton)
1. Fillet the cup-to-tube junction (stress riser) and the motor pad root.
2. Real belt window cut + a finger slot to seat/tension the belt.
3. Output ring + yoke bolt detail (this file stubs the ring as the
   bearing bore; model the 6× output-pin holes to match `out_bc`).
4. Wire channels / strain-relief clips along the tube.
5. Lightening pockets once the load path is confirmed on Proto 2.
```
```

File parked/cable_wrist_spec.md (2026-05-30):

# Fully cable-driven wrist — zero motors past the shoulder

Goal: minimal distal mass. ALL six motors on the J1 turntable; the arm is
structure + Dyneema + idlers. Wrist = a cord-driven differential.
Files: `cable_wrist.scad`. Builds on `capstan_spec.md`.

## Motor census (all on the turntable / base)
| Joint | DOF | Drive | Travel |
|---|-----|---|---|
| J1 base | roll | geared cartridge (fixed base) → turntable | continuous |
| J2 shoulder | bend | capstan cord | ±135° |
| J3 elbow | bend | capstan cord (over J2) | ±135° |
| J4 forearm | roll | capstan cord to a forearm sector | ±135° |
| J5 wrist pitch | bend | **differential cord A/B** | ±100° |
| J6 tool roll | roll | **differential cord A/B** | ±135° |
→ 6 steppers, **none in the arm**. Forearm + wrist carry no motors.

## Weight reality (spend complexity where it pays)
- Removing the **J2/J3 NEMA17s** (~0.28 kg each @ 200–400 mm) is ~90% of
  the moment win — the capstan plan already does this.
- A fully cable wrist removes only the small J4/J6 motors (~0.7 N·m of
  shoulder torque) at the cost of +3 cords, +6 idlers, and full wrist
  coupling. Worth it only if you truly want nothing in the arm.

## The differential (J5 pitch + J6 roll from 2 cords)
Bevel differential, cords turn the side bevels instead of motors:
```
 cord A → side bevel A ┐
                       ├ central bevel on the J6 ROLL (tool) axis
 cord B → side bevel B ┘
 carrier yoke = J5 PITCH axis
   A,B same dir  → ROLL    A,B opposite → PITCH
 firmware:  roll=(a+b)/2   pitch=(a−b)/2     (CoreXY sum/difference)
```
- Side bevels can be printed bevel gears OR cord-and-pulley crosses.
- Each of A, B is a pull-pull loop (two runs) anchored on its side pulley.

## Routing (the 90° conversions)
```
turntable → [J2-concentric idler] → upper arm → [J3-concentric idler]
          → forearm CENTERLINE (on J4 axis, decouples forearm roll)
          → wrist redirect idlers → side bevels / pitch sector
```
- On the **forearm centerline** so J4 roll barely disturbs the wrist cords.
- Pitch sector plane CONTAINS the forearm axis → final turn is mostly
  in-plane; redirect idlers just set the pull-pull tangent points.
- J4 cord taps off earlier to a forearm-base sector (its own ±135°).

## Coupling matrix (output-side encoders calibrate it)
Lower-triangular; each downstream joint picks up upstream terms:
```
θ2 = k·φ2
θ3 = k·φ3 − c32·θ2
θ4 = k·φ4 − c42·θ2 − c43·θ3
[θ5;θ6] = M·[φA;φB] − C45·[θ2..θ4]   (M = differential sum/diff)
```
Calibrate c_ij empirically: move one joint, log the others' encoders.
This is why output-side absolute encoders are non-negotiable here.

## Gotchas specific to the cable wrist
- **Fleet angle:** as the pitch carrier swings, cord entry angle into the
  redirect idlers changes → keep idlers far / use self-aligning (pivoting)
  idlers, or accept reduced pitch range (±100°).
- **Idler count = friction + compliance.** J5/J6 are the least stiff
  joints (most crossings). Fine at 250 g; don't expect machine-tool rigor.
- **Tension coupling:** the differential shares cords A/B between pitch and
  roll — a pretension change affects both DOF. Tension both runs equally.
- **Cable count:** 5 capstan cords (each a pull-pull loop) + terminations
  + tensioners. This is the bulk of the build effort now — plan a tidy
  cable plate on the turntable.

## Pragmatic fallback
If 5-cord routing is too much for v1: cable J2/J3 only (the big win),
keep J4/J5/J6 as small local pancake steppers (NEMA11). Captures most of
the mass benefit; defer the differential + wrist routing to v2.

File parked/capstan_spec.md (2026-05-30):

# Remote 2-stage capstan arm (WAM-class)

Motors on the J1 turntable; steel cables drive the bend joints (J2/J3/J5)
through two capstan stages. Zero backlash, light arm, motors off the
distal links. Files: `capstan_drive.scad`.

## Arm architecture
| Joint | Type | Drive |
|---|---|---|
| J1 base | roll (continuous) | geared cartridge (fixed base), output = TURNTABLE |
| **J2 shoulder** | bend | **remote 2-stage capstan** from turntable |
| **J3 elbow** | bend | **remote capstan**, cable routed over J2 |
| **J5 wrist** | bend | **remote capstan**, cable routed over J2+J3 |
| J4 forearm | roll (continuous) | small roll cartridge on the arm |
| J6 tool | roll (continuous) | small roll cartridge on the arm |

Motors for J2/J3/J5 ride the turntable → **J1 never enters the cable
coupling.** Arm links carry no bend-joint motors → very light.

## Reduction & cable
- 2 stages, **6:1 × 6:1 = 36:1**. Drum r=10 mm, pulley/sector R=60 mm.
- Stage-1 pulley shares a shaft with the stage-2 drum (compound stage).
- Cable: **Dyneema DM20 (UHMWPE), anchored both ends** (terminated
  capstan = zero slip). 5–6 wraps/drum. Confirm cord dia + MBL to finalize
  drum/sector sizes and pretension (see sizing below).
- Dyneema bends to ~5× dia → drums can SHRINK: r_drum 6 mm → sector R 36 mm
  still gives 6:1, so **sector dia ~72 mm** (vs 120 mm with steel). More
  compact joints, smaller footprint. Optional — keep 60 mm for stiffness.
- Output sector arc 270° → **±135° travel**.
- Same big crossed-roller output bearing + output-side encoder as the
  coaxial cartridge — only the reduction element changes.

## Tension / sizing (J2 worst case ~11 N·m) — size by CREEP, not strength
- Stage-2 cable tension = T_out/R_sect = 11/0.06 = **183 N** (at 60 mm
  sector). Stage-1 cable sees ~1/6 (~30 N).
- **Dyneema is plenty strong** — the limit is creep, not break. UHMWPE
  creep accelerates above ~20–30% of MBL, so size the cord so
  **pretension + peak load stays under ~25% MBL**. For ~183 N peak +
  ~80 N pretension ≈ 263 N → want **MBL ≥ ~1050 N** (≈ 100 kg cord).
- Use a **creep-improved grade (SK78/SK99)** and **pre-stretch / heat-set**
  the cord before final tensioning — most of the creep happens early.
- Hub & bearing react ~263 N; solid printed hub fine.

## HARD PART 1 (rewritten for Dyneema) — CREEP, not bend radius
Dyneema bends happily at ~5× dia, so the small-drum fatigue problem is
gone. The new problem is **creep**: under constant pretension the cord
slowly lengthens → pretension drops → slack appears → **lost motion
returns**, killing the zero-backlash benefit you chose capstan for.
Mitigations, in order:
1. **Constant-force tensioner** (spring or weighted) on each cable instead
   of a fixed turnbuckle — it takes up creep automatically and holds
   pretension. This is the single most important change vs steel.
2. **Pre-stretch / heat-set** the cord and run a break-in cycle; re-tension
   once after break-in.
3. Keep working load <25% MBL (above).
4. Output-side encoder still reads true angle, so creep doesn't lose you
   *position* — but slack costs *stiffness*, hence the spring tensioner.
- Still cut a **helical groove, pitch = cord dia**, on every drum.

## HARD PART 2 — routing & kinematic coupling
Cables for J3/J5 cross intervening joints. Route each over an **idler
concentric with the crossed joint's axis** so the joint's rotation maps
to a *known* cable-length change (a coupling term), not slack.

Coupling (output-side, calibrate coefficients from idler/sector radii):
```
θ_J2 = (1/36)·φ_motor2
θ_J3 = (1/36)·φ_motor3  −  c32·θ_J2
θ_J5 = (1/36)·φ_motor5  −  c52·θ_J2  −  c53·θ_J3
```
- This is the CoreXY decoupling problem again — solved in firmware.
- **Output-side absolute encoders make it robust:** they read true joint
  angle regardless of routing, so calibrate `c` empirically (move one
  joint, watch the others' encoders) rather than deriving exactly.
- Idlers add friction & a little compliance per crossing → J5 (2
  crossings) is the least stiff joint. Acceptable for 250 g.

## Tensioning & terminations (Dyneema-specific)
- **Do NOT knot Dyneema** — knots slip and lose ~50% strength. Terminate
  by **splice** (Brummel/locked bury — Dyneema splices beautifully) or by
  **several anchored wraps + a clamp plate / set-screw** in a drum slot.
- One end fixed; the other on a **constant-force spring tensioner** so it
  takes up creep automatically (vs a fixed turnbuckle that goes slack).
- Pre-stretch the cord, run a break-in cycle, re-tension once.
- Radius every groove and anchor edge — Dyneema is abrasion/edge
  sensitive; sharp corners cut it.

## Where capstan does NOT go
Continuous-rotation joints (J1, J4, J6). Anchored cable = finite travel.
Keep those as geared/harmonic cartridges.

## Recommended first prototype (de-risk before the whole arm)
**One remote capstan joint + coupling firmware**, on a bench:
1. Build J3-like: motor + 2-stage on a fixed plate, cable over ONE
   concentric idler (mock J2 axis), to a sector on a crossed-roller race.
2. Verify: backlash (~0, the selling point), output range ±135°,
   cable life under cycling, pretension hold.
3. Mount the idler on a movable "J2" and **calibrate c32** by rotating it
   and logging the sector encoder — proves the decoupling firmware.
Get this one joint right and the arm is just replication + routing.
```
```

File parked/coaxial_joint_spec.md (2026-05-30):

# Clevis-free coaxial joint (modular actuator cartridge)

Eliminates the fork/yoke. The whole drive sits in one drum; the moving
link cantilevers off the output face on ONE big crossed-roller bearing.
Cobot (Universal Robots) architecture. File: `coaxial_joint.scad`.

## Layout (along the joint axis)
```
[geared stepper] -> shaft IN -> [wave gen] inside [flexspline]
   STATOR carries CS (N+2, fixed)            ROTOR carries DS (N, output)
   STATOR holds outer race ─┐   ┌─ ROTOR is the inner race
                       big crossed-roller bearing (OUTBOARD of gears)
   stationary link on STATOR body     moving link bolts to ROTOR face
                                       (offset L-arm, single-sided)
```

## Reduction
`total = geared_stepper_ratio × (N/2)`
- Plain NEMA17 direct → 18:1 (roll joints, low load).
- NEMA17 + 5:1 planetary → **90:1** (bend joints). No belt, fully inline.
- This is the "commonly available geared stepper" path from day one.

## Roll vs bend joints (both clevis-free)
- **Roll (J1/J4/J6):** links coaxial with the drum → straight tube-in,
  tube-out. The cartridge is literally in line.
- **Bend (J2/J3/J5):** stationary link off the stator body, moving link
  is an offset arm off the rotor face → the drum becomes the elbow. No
  fork because the big bearing takes the cantilever moment.

## Why the output bearing grows (and goes outboard)
Single-sided support = this ONE bearing reacts the entire bending moment
in single shear. So:
- **Bigger** than in a clevis (two-bearing) design.
- **Concentric and OUTBOARD of the gears** for max moment arm → stiffest.
- Modeled here as a ~104 mm BB crossed-roller race (Proto 1 part), or a
  bought thin-section slewing ring. This is THE part to validate first.

Moment check (250 g @ 0.45 m ≈ 1.1 N·m payload + arm): a 100 mm race
puts the reaction couple on a 100 mm arm → low ball loads, easily within
a printed BB race. Bigger race = stiffer; cost is package diameter.

## The coaxial-motor tradeoff (read this)
Putting the motor on-axis removes the 2:1 belt pre-stage. Consequences:
1. The single gear stage must supply the whole ratio → use a **geared
   stepper** (above) rather than a 72-tooth/37-pin single stage.
2. The motor occupies the center, so the **output encoder** moves:
   - Keep the wave gen short (it lives in the gear plane only); the rotor
     center stays free at the FRONT → magnet on the rotor center web,
     IC on a thin 2-leg bridge from the stator front rim (NOT a clevis).
   - The moving link bolts on a bolt circle OUTSIDE the bridge, or read
     the magnet from the back if the link covers the front center.
   - Alternative: dual-shaft geared stepper → motor-side magnet on the
     rear stub for commutation; rim ring-magnet for absolute output.
3. Center bore still routes downstream cables near the axis.

## Gearset is swappable (same cartridge)
`coaxial_joint.scad` pulls harmonic rings from `harmonic_ring.scad`. To
run cycloidal instead: replace `internal_ring_gear()` with the pin ring +
disc and put the wave gen's job onto the eccentric cam. Same stator,
rotor, bearing, motor mount, encoder. Prototype both on Proto 2.

## Print / assembly
- Print stator and rotor with the **joint axis vertical** → round bearing
  races and gear bores (roundness drives backlash).
- BB race: load airsoft BBs into the groove on assembly; the rotor traps
  them against the stator. Grease lightly.
- Heat-set inserts for the geared-stepper bolts and the link bolt-face.
- Register the gearset concentricity via the bearing itself (rotor IS the
  inner race) — far better alignment than two bolted links.

## To refine in CAD (skeleton caveats)
1. The BB groove is a single torus here; real crossed-roller needs
   alternating ±45° V-grooves (or use two angular-contact thin-section
   bearings back-to-back instead).
2. Flexspline axial retention + the wave-gen-to-shaft coupling (flat/key).
3. Encoder bridge + magnet web detail; moving-link offset-arm geometry.
4. Seal/dust cover over the gear cavity.

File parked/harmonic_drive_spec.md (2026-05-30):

# Integrated flat strain-wave drive — one ring per link

A **flat (pancake) harmonic** drive split across two arm links. Each link
carries one rigid circular spline printed into it; the flexspline + wave
generator slot in between. Files: `harmonic_ring.scad`.

## Why the flat type (two circular splines)
Standard harmonic = 1 ring + cup flexspline → doesn't split across links.
The **flat type** has TWO rigid rings and a ring flexspline, so:
- **CS (N+2 teeth)** → built into the **housing link** (stationary).
- **DS (N teeth)**  → built into the **next link** (rotates = output).
- Flexspline (N) + wave generator → the slot-in cartridge.

Flexspline regresses 2 teeth/rev vs CS; DS (same count as flexspline)
follows it → **ratio = N/2**.

## Numbers
| Param | Value |
|---|---|
| Flexspline / DS teeth | 36 |
| CS teeth | 38 |
| Module | 2.0 mm |
| Pitch dia (flexspline/DS) | 72 mm |
| Pitch dia (CS) | 76 mm |
| Ring OD | ~93 mm (fits the 98 mm housing) |
| Harmonic ratio | 18:1 |
| + 2:1 GT2 belt | **36:1 total** |
| Wave-gen radial deflection δ | ~1.8 mm (≈0.9·m) |

Keeping the belt pre-stage lets the harmonic do only 18:1 (36 teeth,
2.0 module — easy to print) instead of 72 teeth at ~1 mm module.

## How it slots into `arm_link.scad`
- `internal_ring_gear(N+2)` **replaces `pin_ring_bores()`** in the cup —
  i.e. the CS is the cup's inner wall. No dowels, no cycloidal disc.
- The **next link** prints `internal_ring_gear(N)` as its proximal face.
- The two links register on a **spigot** (see below) and bolt around the
  perimeter — the flexspline lives in the gap, the wave generator on the
  input shaft (same 8 mm shaft + 2:1 belt as before).
- Output-side encoder unchanged: magnet on the DS/output center, fixed
  bridge reads it.

## The two things that make or break a PRINTED strain wave
1. **Flexspline material & wall.** It flexes every rev — this is the wear/
   fatigue part and the reason we earlier preferred cycloidal.
   - **PP (polypropylene):** best fatigue life, flexes happily; hard to
     print (warping, bed adhesion) — use a PP-friendly sheet/glue.
   - **TPU (95A):** easy to print, very durable in flex, BUT high
     hysteresis → torsional wind-up & lost motion. Okay for a runner.
   - **Nylon (PA / PA-CF):** stiffer, decent fatigue; CF makes it too
     stiff — use unfilled nylon for the flexspline.
   - Wall ~1.5 mm at the root; thinner flexes easier but wears faster.
   - Expect **finite life** — design the flexspline as a cheap, fast-
     reprint consumable. This is the honest trade vs cycloidal's steel
     dowels.
2. **CS↔DS concentricity & alignment across the slot-join.** The two
   rings are on two *separate printed parts*. If they're not coaxial and
   square, teeth bind or skip. → a precise **register spigot**:
   - Housing link: a ~60 mm boss (h≈4 mm) concentric with the CS.
   - Next link: a matching bore. Print both vertical so they're round.
   - Bolt circle outside the spigot; the spigot does the centering, the
     bolts only clamp.

## Wave generator options (printed)
- **Roller type (recommended):** oval carrier + 2 ball bearings riding the
  flexspline bore. Lower friction, less heat than a plain oval.
- **Plain oval:** printed ellipse + PTFE/greased flexspline bore. Simpler,
  more friction, fine for a bench test.
- δ ≈ 0.9·m ≈ 1.8 mm radial. Too little → teeth don't engage; too much →
  over-strains the flexspline.

## Backlash / stiffness reality
- Strain wave's selling point is **near-zero backlash** — true if teeth
  fit well. That's the upside over a sloppy-printed cycloidal.
- Its weakness is **torsional wind-up** (the flexspline is a spring). The
  output-side encoder reads the wind-up, so it's great for static
  accuracy, poor for dynamic stiffness. Worse with TPU flexsplines.

## Fallback (don't delete the cycloidal files)
If the printed flexspline disappoints on life or wind-up, the **exact same
housing** takes the cycloidal internals — `pin_ring_bores()` instead of
`internal_ring_gear()`, steel dowels instead of a flexspline. Same 8 mm
input shaft, same belt, same output bearing, same encoder. Prototype both
discs/flexsplines on Proto 2 and keep whichever measures better.

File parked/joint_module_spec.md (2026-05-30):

# Joint module — mechanical stack, BOM & fits

36:1 module = 2:1 GT2 belt pre-stage + 18:1 cycloidal (19 pins / 18 lobes).
Files: `cycloidal_disc.scad` (disc + ring), `joint_module.scad` (cam,
flange), `encoder_joint_spec.md` (sensor).

## Axial stack-up (motor end → output end)
```
 NEMA17 (5mm shaft) ── 20T GT2 pulley
        │  belt, 2:1
        ▼
 40T GT2 pulley ─ INPUT SHAFT (8mm ground rod)
   ├─ 608 + 608 PAIR in the back-wall boss (~18mm apart)
   │       └─ takes the cam cantilever moment AND frees the output
   │          center for the encoder + cable pass-through
   ├─ DOUBLE ECCENTRIC CAM (cantilevered forward off the boss)
   │     ├─ 6802 + DISC 1   (offset +E)
   │     └─ 6802 + DISC 2   (offset −E, 180°)   ← balanced pair
 PIN RING (19× 6mm steel dowels, INTEGRAL to the housing cup wall)
 6× 6mm steel OUTPUT PINS ─ OUTPUT RING (rotates with the next link)
   └─ MAIN OUTPUT BEARING (6810 thin-section, or BB crossed-roller race)
 Next link = YOKE bolted to the output ring's perimeter (center open)
 MAGNET (6×2.5 diametric) on output center ─ fixed ENCODER BRIDGE over it
```

## Bearing / hardware BOM (per joint)
| Qty | Part | Size (mm) | Role |
|----:|---|---|---|
| 2 | 608-2RS | 8×22×7 | input shaft support in housing |
| 2 | 6802-2RS | 15×24×5 | cam journals → disc bores |
| 1 | 6810-2RS *or* BB race | 50×65×7 | **main output (moment) bearing** |
| 19 | dowel pin | 6 Ø × (T+2) | ring rollers (the gear "teeth") |
| 6 | dowel pin | 6 Ø × ~22 | output pins through disc holes |
| 1 | ground rod | 8 Ø input shaft | cam carrier |
| 1 set | GT2 20T + 40T + belt | — | 2:1 pre-stage |
| 1 | NEMA17 | — | motor (run ≤50% holding) |
| 1 | magnet N35 | 6 Ø × 2.5 | encoder target |

Per arm (J1–J3 as this module): ×3. Wrist (J4–J6) uses the lighter
differential — separate spec.

## Critical fits / clearances
- **Cam journal ↔ 6802 bore:** print journal at 15.0; bore is steel.
  Printed-on-steel press is unreliable — add a **0.1 mm shim/CA-glue**
  or model journal at 15.15 and sand to fit.
- **Disc bore ↔ 6802 OD (24):** light slip fit; model `bore_r=12.1`
  if your printer runs tight. Disc must spin freely on the bearing.
- **Ring dowel holes:** `Rr+0.10` in the .scad → press fit for 6 mm
  dowels. The disc rides on the dowels' *inner* faces.
- **Output pin holes in disc:** oversized by E (radius `out_pin_r+E`)
  so the orbiting disc clears the fixed pins. Do **not** tighten these.
- **Backlash budget:** belt (~0.05°), cycloidal (≤0.3° if fits good),
  output-pin clearance (keep pins+holes concentric). Output-side
  encoder reads through all of it — that's the point.

## Balance & assembly notes
- Two discs **180° out of phase** (cam journals at +E / −E) cancel the
  orbital shake; the crescent counterweights in the cam trim the rest.
  Single-disc is fine for a slow bench test, bad above ~60 rpm output.
- Press dowels into the ring first, then drop disc 1 on its 6802, rotate
  cam 180°, drop disc 2. Slide output pins through *both* discs' holes.
- Torque path is shaft→cam→bearing→disc→**output pins**→flange. The cam
  bearing only transmits the small radial orbit force, so a printed cam
  is fine; the output pins see the real tangential load → **steel**.

## Belt pre-stage (`belt_stage.scad`)
2:1 via **20T → 40T GT2 (6 mm)**. Pitch diameters 12.73 / 25.46 mm.

| Closed belt | Center distance C |
|---|---|
| 110 mm | ~24 mm (tight, pulleys nearly touch) |
| **122 mm** | **~30 mm (recommended — compact)** |
| 158 mm | ~49 mm (roomy for tensioner) |
| 200 mm | ~70 mm |

- **Tension by sliding the motor:** the mount has 4 bolt slots + a pilot
  slot along the center-distance axis. Install the belt at the short end
  (slack), slide the motor away, lock the M3s. ~8 mm travel brackets the
  122 mm belt.
- **Belt force check:** motor 0.45 N·m / 6.37 mm pinion radius ≈ **71 N**
  — well within 6 mm GT2's working tension. No need for GT3/3 mm here.
- Buy the pulleys (5 mm bore for the motor, 8 mm bore for the input
  shaft); printing GT2 teeth accurately is not worth it.
- Keep the belt run clear of the encoder magnet — steel belt cords near
  the field skew readings.

## Sanity numbers (shoulder, J2)
- NEMA17 holding ~0.45 N·m × 36 × 0.7 eff ≈ **11 N·m** output.
- Demand ~6 N·m → motor runs ~30% holding → safe open-loop, no skips.
- Output pin tangential force ≈ 11 N·m / (6 pins × 0.018 m) ≈ **100 N**
  per pin → 6 mm steel dowel in shear, trivial.

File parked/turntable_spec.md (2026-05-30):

# Turntable motor-plate layout

J1 motor is fixed to the base and rotates the TURNTABLE. All other motors
ride the turntable, so their cords never cross J1 (no J1 coupling for
J2–J6). Files: `turntable.scad`.

## Motor census
| On | Motor | Drives | Notes |
|----|---|---|---|
| **Fixed base** | J1 | turntable rotation | geared cartridge; vertical axis, inertia-limited only |
| Turntable | J2 | shoulder | 2-stage capstan |
| Turntable | J3 | elbow | cord crosses J2 |
| Turntable | J4 | forearm roll | cord crosses J2, J3 |
| Turntable | W1 | wrist diff A | crosses J2, J3, (J4) |
| Turntable | W2 | wrist diff B | crosses J2, J3, (J4) |
| Turntable | Grip | gripper tendon | crosses all |
→ 6 motors on the turntable + 1 fixed = **7 actuators**.

## Why motors-on-turntable (the deliberate trade)
- PRO: nothing crosses J1 → no J1 coupling, no fleet angle at the base.
- CON: J1 must accelerate ~6 motors of inertia. Fine — J1 is vertical
  (no gravity torque) and heavily geared; size it for base slew rate,
  not holding torque.
- v2 option: move J2/J3 motors to the fixed base, route their cords over a
  J1-concentric idler. J1 coupling is a single linear term (`+k·θ1`) →
  cheap to compensate. Defer until inertia actually bites.

## Plate arrangement
- 6 steppers in a ring (~80 mm radius → ~200 mm plate). Each has its
  2-stage reducer block (stage-1 pulley + stage-2 drum, `capstan_drive`).
- Stage-2 cords exit upward/inward toward a central **shoulder mast**
  carrying the J2 axis.
- Constant-force **spring tensioner per cord** on the plate (Dyneema creep
  — non-negotiable, see capstan_spec). Long runs (J4/W1/W2/grip span the
  whole arm) creep most → these tensioners matter most.

## The cable trunk = stacked concentric idlers (this is the WAM bit)
Every cord is a pull–pull LOOP (2 runs). Run count crossing each joint:
```
cross J2:  J3,J4,W1,W2,grip = 5 loops = 10 runs  (+ J2 itself wraps here)
cross J3:  J4,W1,W2,grip   = 4 loops = 8 runs
cross J4:  W1,W2,grip      = 3 loops = 6 runs
```
At J2 and J3, route every passing run over an idler **concentric with
that joint axis** → the crossing becomes a known linear coupling term, not
slack. In practice that's a **stacked idler pack** on the J2 axis (≈10
grooves) and on the J3 axis (≈8 grooves), one groove per run. Keep groove
order consistent so runs don't cross/rub.

## Coupling (lower-triangular, calibrate with output encoders)
```
θ2 = k·φ2
θ3 = k·φ3 − c32·θ2
θ4 = k·φ4 − c42·θ2 − c43·θ3
[θ5;θ6] = M·[φW1;φW2] − (wrist crossing terms)
```
Calibrate c_ij by moving one joint and logging the others' encoders.

## Electrical
- Motors rotate with the turntable → their wires cross J1. Use a **slip
  ring** (7+ motors × steps/enc = many conductors → a capsule slip ring)
  or a generous **service loop** if J1 travel ≤ ±180°. Encoders are on the
  joints (also cross J1) — same slip-ring/loop.

## Sizing notes
- Long cords (whole-arm runs) → more total creep elongation (∝ length) →
  consider a slightly heavier Dyneema for W1/W2/J4 and definitely the
  spring tensioners.
- Idler count on the long runs adds friction + compliance; W1/W2 (wrist)
  are the softest joints. Acceptable at 250 g.
- J1 inertia: ~6 × NEMA17 (~1.7 kg) at ~80 mm radius + arm. Geared
  cartridge ~90:1 handles it; don't expect fast base slews.

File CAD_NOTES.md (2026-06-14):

# build123d / OCP CAD Notes

Hard-won, reusable lessons from building the integrated-actuator parts in
build123d (OCC kernel). Read this before fighting the geometry — most of the
pain here came from a handful of OCC quirks that have clean workarounds.

The interpreter that has `build123d` + `ocp_vscode` is **pyenv 3.12.9**, not the
system `python3`. Run everything with it:

```bash
/home/dan/.pyenv/versions/3.12.9/bin/python <script>.py
# or just `make ...` — the Makefile's python3 resolves to the pyenv shim
```

---

## 1. Live preview — OCP CAD Viewer in VSCode

The OCP CAD Viewer renders build123d **BREP solids directly** (its own
tessellation), over a local port (default **3939**) in a VSCode webview — so it
works without a special display, unlike the MuJoCo `launch_passive` viewer.

- Install: `pip install ocp_vscode` **into pyenv 3.12.9**, plus the "OCP CAD
  Viewer" VSCode extension (bernhard-42).
- Set the VSCode interpreter to 3.12.9 (Ctrl-Shift-P → *Python: Select
  Interpreter*) so the extension and your scripts agree. `.vscode/` is
  gitignored (its interpreter path is user-specific).

**`preview.py`** wraps `show()` so it's a no-op when `ocp_vscode` isn't installed
(keeps `make`/CI headless-safe):

```python
from preview import show
if __name__ == "__main__":
    show(part())                       # one part
    # show(a, b, names=["body","plate"])  # multiple, toggle-able
```

`arm_assembly.py --show` renders the whole arm. The "viewer is just showing the
logo" state simply means no `show()` has connected yet; it clears on the first
push to 3939.

**Camera "stuck" after a reload** is `reset_camera=KEEP` — the geometry *did*
update; hit the viewer's resize/fit button once.

---

## 2. Live reload — `make watch`

`watch.py` re-runs a part on every save so its `show()` refreshes the viewer:

```bash
make watch                          # default: angle_mount.py
make watch PART=arm_section.py
make watch PART="arm_assembly.py --show"
```

Two watchdog gotchas, both fixed in `watch.py` — note them if you write another
watcher:

1. **Editors save atomically** (write temp + rename), which arrives as
   `created`/`moved`, *not* `modified`. Listening only for `on_modified` misses
   real saves. → handle `on_any_event`.
2. But `on_any_event` also fires `opened` / `closed_no_write` — and **running
   the part opens its own `.py` to read it**, so reacting to those re-runs
   forever (an infinite loop with no input). → react only to write events
   (`created`/`modified`/`moved`), and set the debounce timestamp **after** the
   build finishes (the build is slow enough that events queued during it would
   otherwise re-fire).

---

## 3. Reading imported geometry instead of hardcoding

The vendor parts come in as exact BREP. Query them rather than guessing numbers:

```python
from build123d import GeomType, Axis
cyl = [f for f in solid.faces() if f.geom_type == GeomType.CYLINDER]
f.radius                       # cylinder radius
f.axis_of_rotation             # true axis: .position (origin) + .direction
f.area                         # spot degenerate/sliver faces
solid.bounding_box().max.Z     # real extents (don't trust a constant that drifted)
solid.is_valid                 # PROPERTY, not a method
solid.center(CenterOf.MASS)    # not `.center_of_mass`
```

This is how we found the micro housing's real **inner bore = r18.5 (d37)**, not
the `BORE=17` a constant claimed — and the **OD = r21**, **height 18.2**.

---

## 4. OCC boolean traps (these cost the most time)

### Coincident-face cuts hang OCC — forever
Cutting a cylinder whose radius **exactly matches an existing cylindrical face**
produces coincident/tangent surfaces the boolean engine churns on indefinitely.
Cutting the housing bore at exactly `r18.5` (its real wall) never returns.

> **Rule:** keep cutters off existing faces. To open the bore we cut **r18.0**
> — a deliberate 0.5 mm margin inside the r18.5 wall. `r18.4` also works but
> 0.1 mm near-coincidence is fragile; give it real clearance.

Quick way to spot a hang vs. slowness: a coincident cut doesn't *slow down*, it
**never finishes** — kill it and look for a cutter dimension equal to a measured
face.

### Diff order matters — cut sub-parts *before* unioning
Cutting the bore out of the **whole** assembly (`body + web + base`) slices
through the vendor housing's **internal cycloidal teeth**. Do the relief/bore
cut on the **web alone**, *then* union the body in, so the imported internals are
preserved:

```python
web -= Pos(0,0, body_top/2) * Cylinder(18.0, body_top+8)   # web only
out = body + web + base                                     # teeth intact
```

### A clean union needs real volume overlap
Two solids that merely touch at a tangent line (zero-area contact) won't fuse
into one solid. Give a connecting web genuine overlap into what it joins
(`len(out.solids()) == 1` is the check).

---

## 5. Hull / extend-a-surface

- **No 3D convex hull of solids exists** in build123d, and faking one with
  booleans is a great way to hang OCC. Don't.
- **`make_hull()` is 2D and must run inside `BuildSketch`.** Calling it on loose
  `Plane.XZ * Circle(...)` edges throws scipy `ConvexHull` "flat simplex"
  errors. The working pattern (a tapered web bridging two profiles):

  ```python
  with BuildSketch(Plane.XZ) as sk:
      with Locations((BR/2, BH/2)): Rectangle(BR, BH)   # grip the body flank
      with Locations((BR+GAP, z1)): Rectangle(BASE_T, 4) # pad under the plate
      make_hull()
  web = extrude(sk.sketch, amount=WEB_T/2, both=True)    # give it Y thickness
  ```
  (`Plane.XZ` maps sketch-local `(u,v)` → global `(X, 0, Z)`.)

- **`extrude(face, amount)`** literally pushes one face outward — the simplest
  "extend the surface out":
  ```python
  f = solid.faces().sort_by(Axis.X)[-1]
  out = solid + extrude(f, amount=15)
  ```
- **`loft([a, b])`** skins between two cross-sections, but wants actual
  `Face`/sketch sections (bare planes error). Heavier; use only when the profile
  must morph (circle → rectangle).

---

## 6. Null-triangulation: vanishing faces (countersinks)

**Symptom:** a face is missing in the OCP viewer *and* the STL, and exports warn
`N faces have been skipped due to null triangulation`.

**Cause:** some valid analytic faces — notably the NEMA17 base's **countersink
CONE faces** — come out of STEP with parametrics OCC's mesher (`BRepMesh`) can't
triangulate. The solid is `is_valid == True`; it's a *mesher* limit, not bad
geometry. Tightening `export_stl(tolerance=...)` and `ShapeFix_Shape` **do not
help** (finer tolerance makes it slightly worse). This matters for printing: a
skipped face is a **hole in the STL → non-watertight**.

**Fix:** convert the offending solid to NURBS (cones → splines the mesher
handles), then cache so it's a one-time cost. Implemented in
`arm_section._load()`:

```python
from OCP.BRepBuilderAPI import BRepBuilderAPI_NurbsConvert
healed = BRepBuilderAPI_NurbsConvert(solid.wrapped, True).Shape()
solid  = Solid(TopoDS.Solid_s(healed))      # ~1.3 s; all faces now mesh
```

Diagnosing which faces fail (mesh, then look for null triangulation):

```python
from OCP.BRepMesh import BRepMesh_IncrementalMesh
from OCP.BRep import BRep_Tool
from OCP.TopLoc import TopLoc_Location
from OCP.TopExp import TopExp_Explorer
from OCP.TopAbs import TopAbs_FACE
from OCP.TopoDS import TopoDS
BRepMesh_IncrementalMesh(shape, 0.1, False, 0.5, True)
exp = TopExp_Explorer(shape, TopAbs_FACE)
while exp.More():
    if BRep_Tool.Triangulation_s(TopoDS.Face_s(exp.Current()), TopLoc_Location()) is None:
        ...   # this face will vanish
    exp.Next()
```

For the inverse problem — repairing an *already-meshed* STL (low-tooth gears
undercut to non-manifold) — `trimesh` `merge_vertices + fix_winding +
fill_holes` recovers watertightness.

---

## 7. BREP disk cache (amortize expensive healing)

NURBS-healing costs ~1.3 s per part; doing it every watch-loop save is painful.
So `_load()` caches the healed solid as **BREP** (`out/.vendor_cache/`, keyed on
the STEP's mtime). BREP write/read is ~0 ms and survives the round-trip clean, so
the first build pays once and rebuilds drop back to ~0.6 s.

```python
from OCP.BRepTools import BRepTools
BRepTools.Write_s(solid.wrapped, cache_path)        # write
sh = TopoDS_Shape(); BRepTools.Read_s(sh, cache_path, BRep_Builder())  # read
```

> **IP note:** the cache holds vendor-derived geometry. `out/` is **gitignored** —
> verify with `git check-ignore out/.vendor_cache/<x>.brep`. Only the two
> permitted vendor STLs may ever be tracked (see `NOTICE`).

---

## 8. Headless inspection without VSCode

When you can't open the OCP viewer (agent/CI), export STL, parse the triangles,
and plot projections with matplotlib — fast enough to eyeball collisions,
clearances, and "is the bore open" questions:

```python
# parse binary STL -> (n,3,3) triangle array, then ax.fill(t[:,0], t[:,1]) etc.
# top view (X-Y) shows whether a web intrudes into a bore;
# side (X-Z) shows cap/lip collisions; Poly3DCollection gives a rough iso.
```

A top-down (down +Z) projection over the bore circle is the quickest check that
a web/relief actually cleared the interior.

---

## 9. Misc build123d / environment

- `np.ptp(arr)`, not `arr.ptp()` (removed in numpy 2.0).
- `MjsLight` has no `directional` attribute — use a positioned point light.
- Interactive MuJoCo (`launch_passive`) must run on the user's display
  (`! python sim/view.py`); it fails from agent context. The OCP viewer does not
  have this limitation.

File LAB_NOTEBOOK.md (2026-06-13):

# Lab Notebook — Process Variables

Running log of the **process variables** that affect how this design prints,
assembles, and performs — kept so the eventual write-up has the real history,
not a reconstruction. Two parts: a **variable catalog** (the systematic list,
updated in place) and a dated **log** (observations as they happen).

Convention: dates absolute (YYYY-MM-DD). Record the *observation* and the
*conditions* even when you don't yet know the cause — correlations emerge later.

---

## Variable catalog

### Print / process
| Variable | Why it matters | Current / baseline | Status |
|---|---|---|---|
| **Filament brand** | Shrinkage, melt viscosity, diameter tolerance differ brand-to-brand even within PLA; a flow calibration doesn't transfer | Bambu PLA (baseline prints) → **Elegoo black PLA** (new) | switching; needs recal |
| **Color / pigment** | Carbon black shifts thermal absorption + flow; black often runs oozier, loses a touch more dimension on small features | black | suspected fit shift |
| **Print orientation** | Hole axis **vertical** → round, slightly undersize; **horizontal** → top sags, undersize + egg-shaped (tighter, out-of-round) | per-part, see notes | key var for the angle part |
| **Flow rate / extrusion mult.** | Directly sets hole/bore size; per-material | calibrated on Bambu | re-cal for Elegoo |
| **Pressure advance** | Corner/seam dimensional accuracy | (record per material) | — |
| **First-layer elephant's foot** | Squishes the bed-facing face → that face's holes/edges shrink | slicer compensation? | enable for seating face |
| **Nozzle temp** | Flow, ooze, small-feature fidelity | (record) | — |
| **Layer height / nozzle Ø** | Small-feature resolution (e.g. countersink chamfers, thin walls) | (record) | — |

### CAD clearances (design levers — see `angle_drive.py`, `arm_section.py`)
| Variable | Meaning | Current |
|---|---|---|
| `GAP` | body OD → mounting plate clearance | 2.0 mm (angle_drive, tuned) |
| `CLEAR` | motor-to-cap gap (sets plate lift `PLATE_Z`) | tuned per drive |
| `CAP` | cyclo end-cap height allowance | tuned per drive |
| `CAP_R` | cap-lip relief radius in the web (= body OD + margin) | `BR + 1.5` |
| bore clear | web cut to open the body interior; r18.0 (wall is r18.5) | 18.0 mm |
| `WEB_T` | hull-web thickness (Y) | 28.0 mm |
| *(proposed)* `FIT` | single per-part print-fit offset for all holes/bores | not yet added |

### Measured hardware (calibration anchors for the model)
| Quantity | Value | Notes |
|---|---|---|
| Holding torque (slip onset) | 1.8 kg @ 75 mm ≈ **1.32 N·m** | limited by **stepper missing steps**, not the printed cyclo slipping (electrically tunable) |
| Static push, measured | 250 g @ 75 mm ≈ **0.18 N·m** | on a scale, arm pushing down |
| Actuator mass | 188 g | full micro actuator |
| Segment length | 75 mm | joint-to-joint (short test build) |

---

## Open questions
- How much of the angle-part fit shift is **material (Elegoo black)** vs
  **orientation**? → isolate by printing the same part in Bambu at the same
  orientation, and the Elegoo at two orientations.
- Is a single `FIT` clearance constant enough, or do the two orthogonal faces of
  the L-part need **independent** offsets (because one prints vertical, one
  horizontal)?
- Does the NURBS-healed countersink print cleanly, or does the chamfer still need
  a slicer-side tweak?

---

## Log

### 2026-06-13 — angle_drive fits differ from the straight sections
- Observation: tolerances on the right-angle part (`angle_drive`) feel "a little
  different" than the straight arm sections.
- Two changes coincided: (1) **material** switched Bambu → Elegoo black PLA;
  (2) the part is an **L** with mating features on two orthogonal faces.
- Hypothesis (orientation): no single bed orientation puts both the cyclo
  bore/boss *and* the NEMA plate holes in the favorable **vertical** axis — so
  one set always prints in the saggy **horizontal** orientation (undersize,
  egg-shaped). The straight sections don't have this conflict, which is likely
  why their fits were fine.
- Hypothesis (material): flow calibrated on Bambu; Elegoo black likely needs its
  own flow / temp cal — expect ~0.05–0.15 mm size drift on holes until redone.
- Next: print a **tolerance ladder** (holes at +0.0/+0.1/+0.2/+0.3 mm) in Elegoo
  black; measure which drops onto the hardware. That offset = the per-material
  `FIT`. Orient with the tightest-tolerance feature (bore/boss) vertical.
- CAD status: `angle_drive` geometry frozen for now (hull web + cap relief +
  web-only bore clear, committed `19f0802`). No `FIT` param added yet.

### 2026-06-13 — flat printing nails the dimensions; Bambu edges out Elegoo
- **Flat on the bed → dimensions are perfect.** Strong support for the
  orientation hypothesis: when the part lies flat so the critical features print
  in the favorable (vertical-axis / no-overhang) orientation, fits land on the
  nominal CAD numbers — no offset needed.
- **Bambu PLA prints a little better than Elegoo black** (surface/dimensional).
  So part of the angle-part drift is material, but orientation is the dominant
  lever — get the part flat and the Elegoo is usable too.
- Takeaway for the angle part: prefer the **flat orientation** that puts its
  tightest feature true; the residual material difference is small enough that a
  per-material `FIT` may not even be needed if it's printed flat.
- Implication for design: where a feature *must* print in a poor orientation
  (the L-part's second face), that's where a `FIT`/clearance offset earns its
  keep — not globally.

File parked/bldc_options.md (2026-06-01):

# BLDC motor options — comparison for a joint actuator

Working question: can a BLDC replace a NEMA 17 at a joint? Yes, as a *frame*
— but **KV (winding) decides how much reduction you need and how hot it runs
holding a pose.** This compares candidates across the markets, because the
low-KV motors you want are *not* in the drone catalog you've been browsing.

## Why you only ever see 2000+ KV
You've been searching the **RC / racing** market. Those motors swing small
props at huge rpm on 4S → few turns of fat wire → **high KV by design**.
Low-KV motors live in other markets and are often spec'd by *turns* (e.g.
"120T"), not KV:

| Market | Typical KV | Why |
|---|---|---|
| FPV / racing quad | 1700–2700 | speed, small props, low V |
| Cinelifter / big quad | 400–900 | bigger props |
| **Gimbal** | **~70–400** | hold a camera still at 0 rpm — *our problem* |
| **Robotics QDD / ODrive** | **80–270** | torque at low speed, legged robots |
| Hoverboard / e-bike hub | 8–30 | direct-drive traction |

**Physical coupling:** KV ∝ 1/turns, and a *small* frame can't fit many
turns → small frames are almost always high-KV. To get low KV you go
**bigger frame**, **rewind**, or **accept a large reduction** (see below).

## Key relation
`Kt [N·m/A] = 8.27 / KV`  → torque per amp. Low KV = high Kt = **less current
to make torque = less heat holding a pose** (the BLDC's weak spot).

Output torque per amp = `Kt × reduction × efficiency` (η≈0.7 assumed).

## Candidate comparison
Specs are **approximate / representative** — verify against the actual part
before committing. "Hold I" = motor current to hold **3 N·m at the joint**
(a realistic arm-joint gravity load) at the listed reduction.

| Motor | Market | OD×H (mm) | Mass | KV | Kt (mN·m/A) | Reduction | Out τ/A | Hold I for 3 N·m | Verdict |
|---|---|---|---|---|---|---|---|---|---|
| Racerstar 2204-1400KV (linked) | racing | 28×18 | ~28 g | 1400 | 5.9 | 30:1 | 0.12 N·m/A | **24 A** ✗ | cooks at stall unless R≫100 |
| 2204 @ huge reduction | racing | 28×18 | ~28 g | 1400 | 5.9 | **360:1** | 1.49 N·m/A | ~2 A | works, but 2-stage gearbox |
| GBM2804 gimbal | gimbal | 28×15 | ~50 g | ~300 | 27.6 | 30:1 | 0.58 N·m/A | ~5.2 A | small but low-KV; modest hold |
| iPower GBM4108-120T | gimbal | 46×25 | ~110 g | ~110 | 75 | 30:1 | 1.58 N·m/A | ~1.9 A | **great holder**, light |
| ODrive D5065-270KV | robotics | 50×65 | ~420 g | 270 | 30.6 | 20:1 | 0.43 N·m/A | ~7 A | heavy; high speed |
| ODrive D6374-150KV | robotics | 63×74 | ~600 g | 150 | 55 | 20:1 | 0.77 N·m/A | ~3.9 A | strong, heavy |
| T-Motor U8-100KV | robotics QDD | 96×35 | ~240 g | 100 | 82.7 | **8:1** | 0.46 N·m/A | ~6.5 A | low-R direct-drive style |
| T-Motor U8 @ higher R | robotics QDD | 96×35 | ~240 g | 100 | 82.7 | 30:1 | 1.74 N·m/A | **~1.7 A** ✓ | ideal holder, but 96 mm OD |
| MAD M6C12-80KV | robotics | ~64×25 | ~200 g | 80 | 103 | 20:1 | 1.45 N·m/A | ~2.1 A | low-profile pancake-ish |
| — NEMA 17 (baseline) | stepper | 42×48 | ~280 g | — | — | 30:1 | — | holds w/ detent, ~0 active I | reference |

## The trade this exposes
There are two ways to make a BLDC hold a pose without overheating:

1. **Low-KV motor + modest reduction** (gimbal / robotics motors, ~20–30:1).
   Holding current ~2 A → manageable heat. Costs: motor is bigger/heavier
   and pricier, but the drivetrain stays simple (single cycloid stage).
2. **Cheap high-KV racer + big reduction** (e.g. 2204 at ~300–360:1).
   Motor is 28 g and \$15, but you need a **two-stage** reduction → more
   backlash sources, more mass/complexity in the gearbox, and the output
   bearing still governs. Against "simple to build/tune."

**Sweet spot for this arm:** a **low-KV gimbal motor (~46 mm, ~110 g, 120T)**
or a **flat robotics motor (MAD/CubeMars-class, ~80 KV)** at ~20–30:1 through
the existing cycloid. Roughly NEMA-17 mass or less, holds at ~2 A, single
reduction stage, and the bell gives a direct mount for the eccentric cam.
The 2204 is best kept for the **gripper / wrist-roll** (light, fast, low
holding load) where its high KV isn't a liability.

## What to check on any candidate
1. **KV** — want Kt high enough that holding current is ~1–3 A at your
   reduction (use the formula above).
2. **Stall thermal mass** — iron/copper mass + can area; gimbal/robotics
   motors are wound to survive 0-rpm current, racers assume propwash.
3. **Bell bolt circle** — outrunner: somewhere to bolt the eccentric cam.
4. **Bearing** — motor bearings are light; let the cycloid input bearing
   carry the eccentric load, motor supplies torque only.
5. **Hollow shaft / through-bore** — nice for routing the dress-pack on-axis.

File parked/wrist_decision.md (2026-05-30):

# Wrist mechanism — trade study & decision

Goal: provide the end-of-arm orientation DOF for a printed, cable-driven
arm (250 g payload), driven by simple remote capstans.

## Options evaluated
| Mechanism | Input/actuator | Range | Backlash | Sensing | Printable | Verdict |
|---|---|---|---|---|---|---|
| **Bevel differential** | **1-DOF capstan pulley** | large | gear lash (small, low-load joint) | per-axis encoder (easy) | yes | **CHOSEN** |
| ABENICS cross-spherical | **2-DOF articulated drive** | full/continuous | gear lash | 3-DOF (hard) | no (lab part) | rejected |
| Roller-driven sphere | 1-DOF | full/continuous | none | 3-DOF + slip (hard) | preload-sensitive | rejected |
| Agile Eye (spherical parallel) | 1-DOF | limited tilt cone | none | coupled legs | precise curved links | rejected |

## Why bevel differential wins for THIS build
- Each input is a plain spinning cord pulley (single DOF) — drivable by
  two simple forearm capstans, no drive element has to reorient.
- Backlash is only at the wrist (lowest load, output encoder watches it) —
  the one place the zero-backlash rule can be relaxed.
- Per-axis absolute encoders → no exotic orientation sensing.

## Why ABENICS was rejected (record so we don't revisit)
Each CS-gear drive module is itself ~2-DOF: the drive gear must tilt to
stay meshed as the ball reorients (differential pinion + helical linkage
per module). No off-the-shelf 2-DOF drive exists; building two of them to
power one ball defeats the purpose. Brilliant mechanism, not DIY-buildable.

## U-joint roll shaft — CONSIDERED & REJECTED (backlash)
A driveshaft + Cardan through the hollow central bevel would give a
positive, full-range 3rd axis — BUT it stacks bevel-mesh lash + printed
Cardan lash right at the tool. That betrays the project's zero-backlash
premise. Rejected.

## Wrist trilemma: zero-backlash · 3-DOF · simple — pick 2
- bevel + U-joint = 3-DOF + simple, but BACKLASH (rejected).
- The zero-backlash way to cross the bend is ANOTHER TENDON, not a shaft:
  a cord over an idler CONCENTRIC with the pitch axis (no length change
  with pitch, always in tension, full range).

## Direction: drop the bevel gears → PURE-CABLE wrist (zero backlash)
- **Cable differential (2 cords) → pitch + yaw** (no gears → no gear lash).
- **3rd cord pair over the pitch-concentric idler → roll** = full 3-DOF,
  zero lash, all forearm-driven (the WAM wrist). Cost vs bevel+U-joint is
  +1 cord pair, +1 idler, +1 coupling term — NOT backlash.

## Open sub-decisions
1. **6-DOF (3 cord pairs) vs 5-DOF (2 cord pairs, add 3rd later)** — same
   pure-cable mechanism; the third axis is incremental.
2. Pure-cable differential routing detail (fleet angle, anchor/tension).

## Industrial reference (why we still chose cable)
Classic industrial wrists (e.g. FANUC) use **concentric coaxial drive
tubes + spiral bevel gears**: wrist motors on the forearm, power
transmitted out to the 3 wrist axes through nested shafts; hollow center
for the dress-pack. Same architecture as ours (proximal motors → concentric
transmission → 3-DOF wrist). But their near-zero backlash comes from
**precision-ground hardened steel** bevels — not reproducible in print.
Cables are our spiral-bevel substitute: low backlash from tension instead
of from grinding. Confirms the topology; reaffirms cable over printed gears.

## Status
Mechanism: LOCKED = cable-driven bevel differential.
Geometry skeleton: `wrist_differential.scad`.
Remaining: resolve the two sub-decisions above, then detail real bevel
teeth (gear library), yoke, bearings, encoder mounts.

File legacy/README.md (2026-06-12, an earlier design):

# legacy/ — deprecated OpenSCAD sources

OpenSCAD is **no longer the CAD toolchain** for this project — the CAD has moved
to **[build123d](https://build123d.readthedocs.io)** (Python + OCC), which
imports the vendor STEP files as exact solids instead of meshes. These `.scad`
files are kept for reference only and are **not maintained**.

| file | status |
|---|---|
| `arm_section.scad` | superseded by [`../arm_section.py`](../arm_section.py) |
| `cycloid_joint.scad` | the from-scratch parametric cyclo joint (3-DOF track); no build123d port yet |
| `arm_trunk.scad` | the 3-DOF from-scratch assembly; uses `cycloid_joint.scad` |

To render the legacy parts you still need [OpenSCAD](https://openscad.org), e.g.
`openscad -o /tmp/x.png -D 'PART="upper"' legacy/arm_section.scad` (it imports
`../vendor/micro/*.stl`).

Older exploration `.scad` (cable drive, wrist, BLDC, harmonic) lives separately
in [`../parked/`](../parked/) and is also OpenSCAD-era.

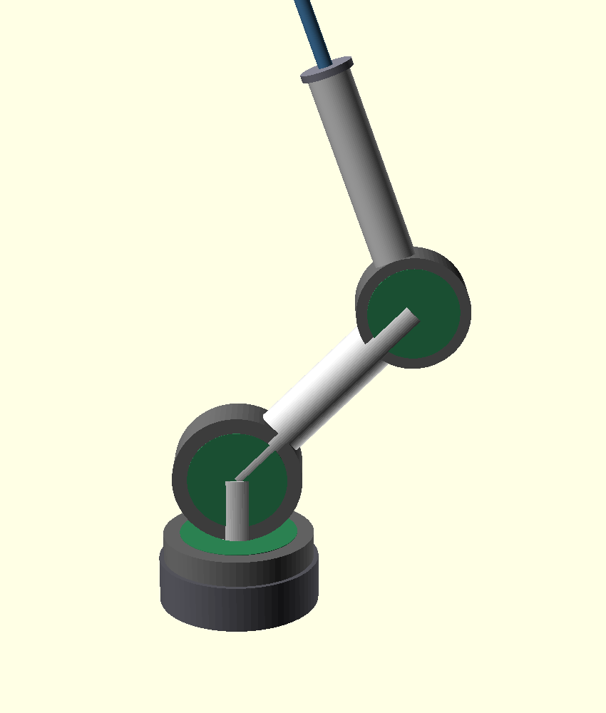
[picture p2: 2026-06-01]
images/arm_trunk.png

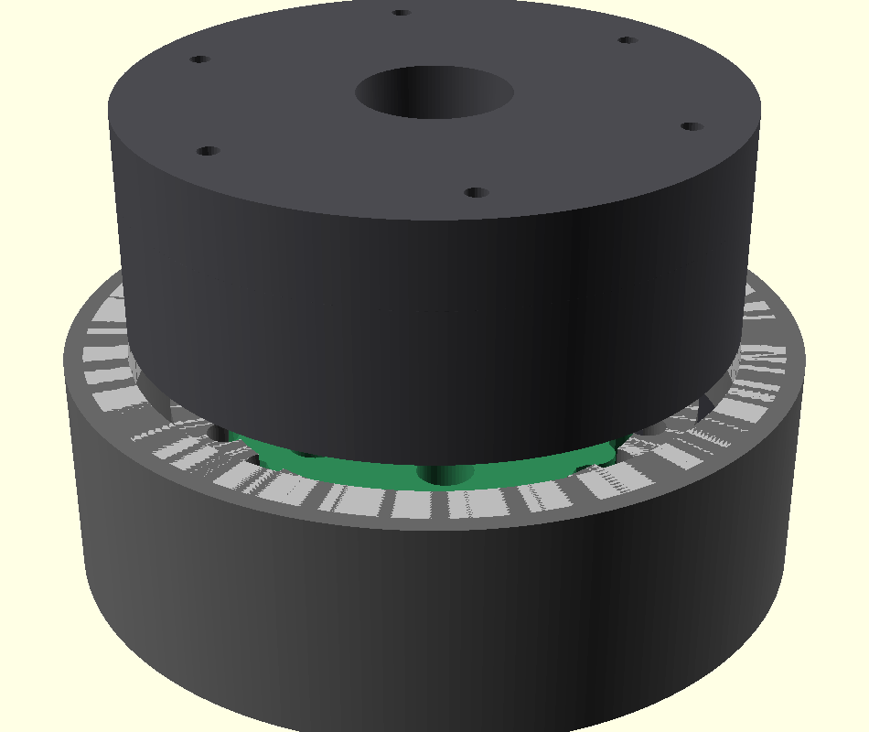
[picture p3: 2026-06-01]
images/cycloid_joint.png

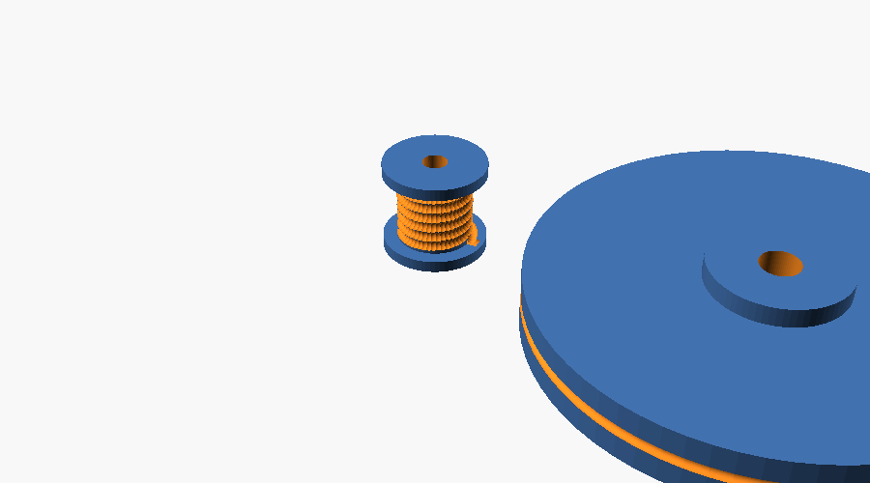
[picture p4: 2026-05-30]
parked/capstan.png

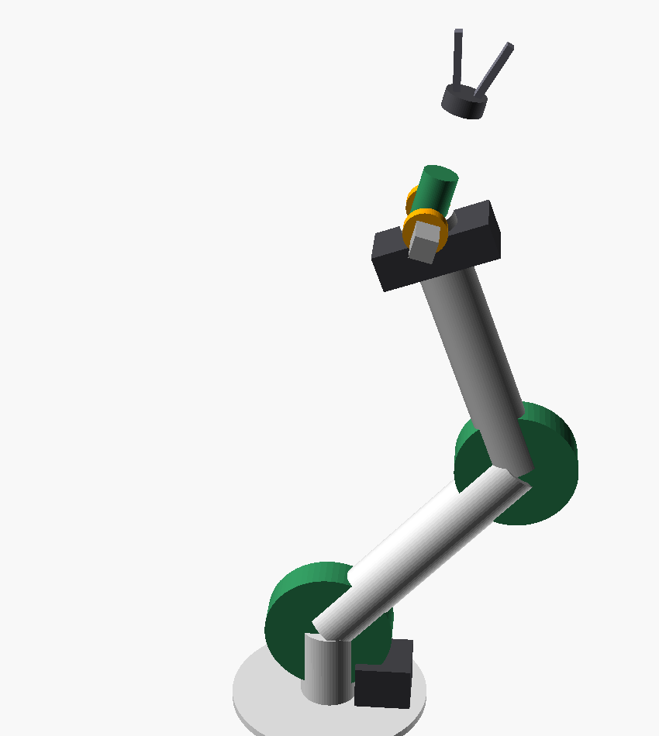
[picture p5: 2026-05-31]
parked/arm_v1.png

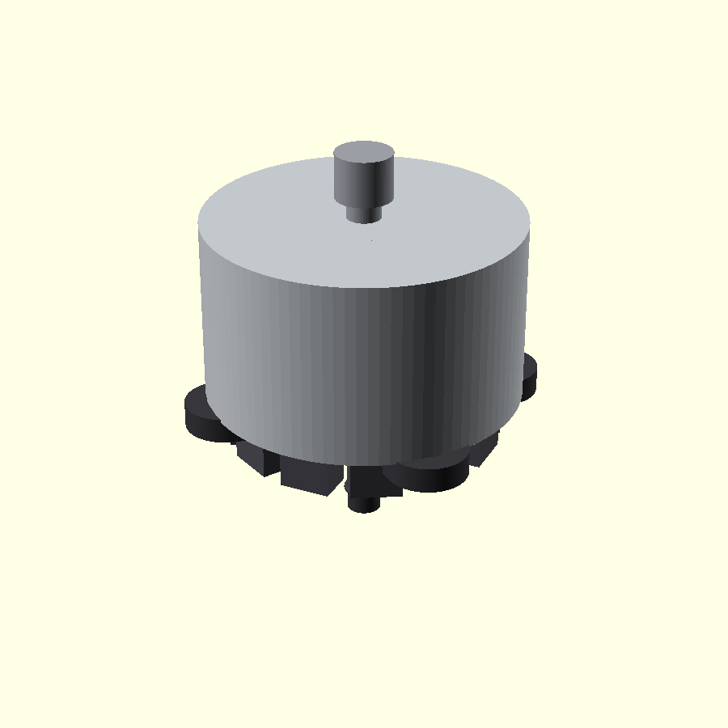
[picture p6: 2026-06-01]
parked/bldc_2204.png

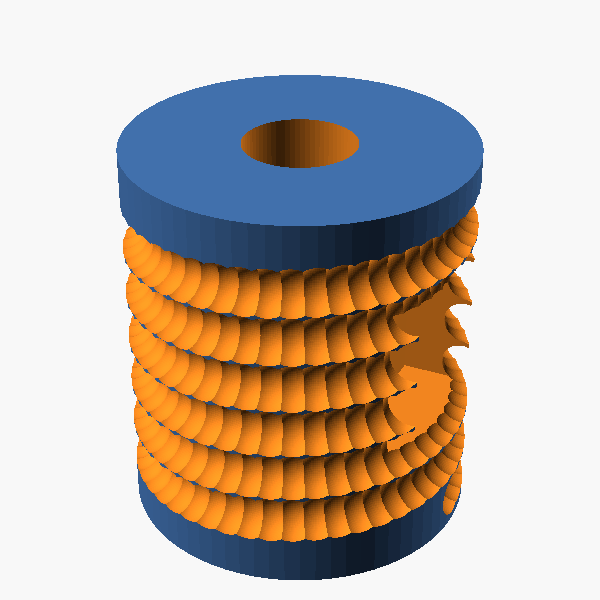
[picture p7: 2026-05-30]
parked/capstan_drum_only.png

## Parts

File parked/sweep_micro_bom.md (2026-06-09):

# Sweep Dynamics — 20:1 Micro Cycloidal — parts list

Reference actuator being evaluated as a buildable cycloidal drive (NEMA17-mount,
~20:1, 3D-printed body + commodity bearings/bolts). Files downloaded as STEP +
print-ready STL (9-disc clearance ladder). This is the **hardware shopping list**.

> Source: Sweep Dynamics (sweepdynamics.com). Drive uses a paired thin-section
> ball bearing for the output (not a crossed-roller), 6 shoulder-bolt output
> pins riding aluminium rollers, and a printed lobed pin-ring. The disc ships in
> 9 clearance variants (−0.1 … Nul … +0.1 mm in 0.025 steps) — print the set,
> fit-test, keep the backlash you want. (Independent confirmation of our own
> clearance-sets-backlash strategy.)

## Bearings — need to buy
Clean `amazon.com/dp/<ASIN>` links (affiliate/tracking stripped); click → **Add to List**.

| Bearing | Designation | Qty | ASIN | Link |
|---|---|---|---|---|
| 30×37×4 mm 2RS | uxcell **6706-2RS** | 2 | B0D6WDB21H | https://www.amazon.com/dp/B0D6WDB21H |
| 7×13×4 mm 2RS  | uxcell **687-2RS**  | 2 | B0D2LBCKP2 | https://www.amazon.com/dp/B0D2LBCKP2 |
| 8×12×3.5 mm 2RS| uxcell **MR128-2RS**| 2 | B0CM6R2Z75 | https://www.amazon.com/dp/B0CM6R2Z75 |

- **30×37×4 (6706)** — main output bearing (×2, likely paired to take the moment).
- **7×13×4 (687)** — eccentric-cam / input support.
- **8×12×3.5 (MR128)** — secondary cam / support.

## Output-pin rollers — substituted to nylon
BOM calls for **M3 × 5mm OD × 10mm aluminium rollers** (×6). The exact
3mm-bore × 5mm-OD × 10mm *plain-bore* aluminium part is an AliExpress
specialty — US retail only stocks threaded (won't spin) or 6mm-OD (wrong
pin diameter). Substituted to **nylon**, which matches our floating-roller
design decision and spins freely on the M3 shank:

| Part | Spec | ASIN | Link |
|---|---|---|---|
| Nylon round spacer, **unthreaded** PA66 | OD 5mm · ID 3.2mm · L 10mm (×6) | B074N5HD42 | https://www.amazon.com/dp/B074N5HD42 |

Electronics-Salon assortment box (2–20mm lengths; use the 10mm). 5mm OD is the
functional dimension (fits disc output holes); 3.2mm bore = ~0.2mm clearance on
the M3 shank so it rolls. Bulk single-length alt: VXB 300-pc M3 unthreaded kit.

## Bolts — already have / per BOM
- M3×20 mm button-head ×6 — output pin bolts (rollers ride on these)
- M3×8 mm countersunk ×4
- M3 nuts ×6

## Print settings (from Sweep instructions)
0.20 mm layer (0.25 initial) · 3–4 walls · 7/7 top/bottom · 25–30% gyroid/grid infill.

---
*Files in `~/Downloads/cad-files/sweep-micro-cycloidal.zip`. The 26:1 High-Torque
variant (62 mm, 40×52×7 output bearings) is in `sweep-cycloidal.zip`.*

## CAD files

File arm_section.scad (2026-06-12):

// ============================================================
//  arm_section.scad — the printable arm links for the cycloidal arm.
//
//  ARCHITECTURE (decided 2026-06): the arm is built from SECTIONS that each
//  integrate one half of a joint at each end. The Sweep Dynamics actuators
//  have a ROTATING BODY (the cyclo Housing is the output) and a fixed motor
//  mount (the NEMA17 Base), and ship with NO external mounting pattern -- so
//  the mount is designed straight into the printed section (fused, not bolted):
//      - one end: the rotating HOUSING (output of the UPSTREAM joint) FUSED
//        into the print  -> this end pivots with the joint.
//      - other end: the NEMA17 BASE plate (motor mount for the DOWNSTREAM
//        joint), also fused in.
//  A joint forms in the gap between two sections: motor on section N's Base
//  -> cyclo internals (discs/shaft/endcap) -> Housing fused into section N+1
//  -> N+1 swings.   Every joint = the 20:1 Micro Cycloidal (42x42, NEMA17)
//  EXCEPT the base slew (the larger 26:1, 62x62), which the base section
//  bolts onto through a right-angle flange.
//
//  FOUR sections (set PART below):
//    "base"    90deg: NEMA17 plate (shoulder motor) + 4-bolt flange -> slew
//    "upper"   long : Housing (shoulder out) ---150mm--- Base (elbow motor)
//    "forearm" long : Housing (elbow out)   ---150mm--- Base (wrist motor)
//    "wrist"   90deg: Housing (wrist-pitch out) + tool-roll actuator mount
//
//  Vendor geometry imported from vendor/micro/*.stl. Native parts sit at
//  XY=(75,0), z=0..h; helpers recenter them on the origin and on Y.
//
//  Local frame: arm length runs +X. Joint (cyclo) axes run along Y (pitch
//  axis). +Z = up; gravity sag bends the beam about Y, so the beam is TALL
//  in Z (stiffness ~ height^2) and only actuator-wide in Y.
// ============================================================

PART = "upper";          // "base" | "upper" | "forearm" | "wrist"

// ---- vendor micro actuator (20:1) ----
ACT      = 42;           // actuator footprint (square, mm)
ACT_R    = 21;           // housing outer radius (round body)
HOUS_H   = 18.2;         // housing height (along its axis)
BASE_H   = 9.0;          // base plate thickness
VC       = 75;           // vendor parts centered at X=VC in their STL

// ---- structural beam (tall in Z to fight gravity sag) ----
SEG_LEN  = 150;          // long-section length (housing center -> base face)
BEAM_H   = 28;           // beam height (along Z) -- the stiff direction
BEAM_W   = 20;           // beam width (along Y) -- ~ actuator width
WALL     = 4;            // collar/gusset wall

$fn = 64;

// ---------- vendor parts, recentered to origin (axis = +Z) ----------
module v_housing() translate([-VC,0,0]) import("vendor/micro/housing.stl");
module v_base()    translate([-VC,0,0]) import("vendor/micro/base_nema17.stl");

// Housing as a joint OUTPUT: cyclo axis along Y, centered on Y=0.
// native (after recenter) z:0..HOUS_H about origin -> rotate so axis=Y, then
// shift so the body straddles Y=0.
module housing_end() translate([0, HOUS_H/2, 0]) rotate([-90,0,0]) v_housing();

// Base as a motor mount: motor axis along Y, plate centered on Y=0.
module base_end() translate([0, -BASE_H/2, 0]) rotate([90,0,0]) v_base();

// flat tall beam from x0 to x1, centered on Y=0
module beam(x0, x1)
    translate([x0, -BEAM_W/2, -BEAM_H/2]) cube([x1-x0, BEAM_W, BEAM_H]);

// collar that grips the housing wall (annulus biting 2mm into the 4mm wall,
// outer face proud for the beam to fuse onto). Bore (r<BORE_R) stays clear.
BORE_R = 17;             // housing inner bore (disc cavity) radius
module housing_collar() {
    rotate([-90,0,0]) translate([0,0,-HOUS_H/2])
    difference() {
        cylinder(h=HOUS_H, r=ACT_R+WALL);
        translate([0,0,-0.5]) cylinder(h=HOUS_H+1, r=BORE_R+2);   // keep cavity clear
    }
}

// triangular gusset blending the beam down onto the base plate face
module base_gusset(xface) {
    hull() {
        translate([xface-0.1, -BEAM_W/2, -BEAM_H/2]) cube([0.1, BEAM_W, BEAM_H]);
        translate([xface-BEAM_H, -BEAM_W/2, -BEAM_H/2]) cube([0.1, BEAM_W, 0.1]);
    }
}

// ---------------- sections ----------------

// LONG section: housing (proximal, X=0) --beam--> base (distal)
module long_section(len=SEG_LEN) {
    xbase = len;                       // base plate face sits at X=len
    union() {
        housing_end();
        housing_collar();
        beam(BORE_R, xbase);           // beam starts at the bore wall (clears the disc cavity)
        base_gusset(xbase);
        translate([xbase, 0, 0]) base_end();
    }
}

if (PART == "upper" || PART == "forearm")
    long_section();

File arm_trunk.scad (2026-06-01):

// ============================================================
//  arm_trunk.scad — THE near-term build target: 3-DOF cycloid trunk.
//
//  J1 (base yaw) + J2 (shoulder) + J3 (elbow), ALL the same cartridge
//  from cycloid_joint.scad at three sizes. No wrist, no cables, no BLDC —
//  those are parked/ explorations. Three joints position the TOOL POINT in
//  space; bolt a fixed gripper or a manual wrist onto the forearm flange.
//
//  J1's output bearing IS the moment bearing (sized up) — the base is just
//  this cartridge stood vertical on a pedestal.
//
//  Joint envelopes are derived from cycloid_joint.scad's cfg() so sizes
//  stay in sync with the real parts. Pose with q1/q2/q3. F5 in OpenSCAD.
// ============================================================

use <cycloid_joint.scad>     // cfg() + accessors + (modules)

$fn = 72;

// ---- link lengths (mm) ----  reach from shoulder ~= a1+a2+tool
H_ped = 40;     // base pedestal height (table -> J1)
H_mast= 70;     // J1 deck -> J2 axis
a1    = 210;    // upper arm  (J2 -> J3)
a2    = 210;    // forearm    (J3 -> tool flange)
tool  = 60;     // forearm flange -> tool point

// ---- pose (deg) ----
q1 = 20; q2 = 45; q3 = -65;

// joint envelope drawn from its real config (bearing OD + ring + motor)
module joint_envelope(j) {
    c = cfg(j);
    brgOD = 2*(c_raceR(c)+c_ball(c)/2)+2;
    ringOD= 2*(c_R(c)+c_Rr(c)+4);
    H = c_T(c)*2 + 0.5 + 6 + c_brgW(c) + 8;
    color("dimgray")  cylinder(h=H, d=brgOD, center=true);            // cartridge body
    color("seagreen") cylinder(h=H+1, d=ringOD, center=true);          // gear ring band
    color([.18,.18,.2]) translate([0,0,-H/2-19]) cube([42.3,42.3,38],center=true); // NEMA17
}
module link(L, od) {
    color("gainsboro") difference() {
        cylinder(h=L, d=od); translate([0,0,-1]) cylinder(h=L+2, d=od-7); }
}

// ---- kinematic chain ----
// base pedestal
color([.35,.35,.38]) cylinder(h=H_ped, d=2*(c_raceR(cfg("J1"))+8));

translate([0,0,H_ped]) rotate([0,0,q1]) {           // ---- J1 base yaw (vertical axis)
    rotate([0,0,0]) joint_envelope("J1");
    color("gainsboro") translate([0,0,8]) cylinder(h=H_mast, d=46);    // shoulder mast
    translate([0,0,8+H_mast]) rotate([0,q2,0]) {     // ---- J2 shoulder (axis = Y)
        rotate([90,0,0]) joint_envelope("J2");
        link(a1, 42);
        translate([0,0,a1]) rotate([0,q3,0]) {       // ---- J3 elbow
            rotate([90,0,0]) joint_envelope("J3");
            link(a2, 36);
            translate([0,0,a2]) {                    // ---- forearm tool flange
                color([.5,.5,.55]) cylinder(h=6, d=44);
                color("steelblue") translate([0,0,6]) cylinder(h=tool, d=12);  // tool stub
            }
        }
    }
}

echo(str("trunk: 3-DOF | reach from shoulder ~", a1+a2+tool,
         " mm | shoulder height ~", H_ped+8+H_mast, " mm"));

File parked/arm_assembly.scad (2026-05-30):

// ============================================================
//  arm_assembly.scad — WHOLE-ARM VISUALIZATION (standalone)
//
//  6-DOF cable-driven arm, posed. Stylized for overview — dimensions
//  follow the specs, but gears/cords are simplified. Open in OpenSCAD,
//  F5 to preview, drag to orbit. Edit q1..q6 + grip to pose it.
//
//  Architecture shown:
//    fixed BASE ─ J1 yaw ─ TURNTABLE (6 motors ride here) ─ shoulder mast
//    ─ J2 shoulder ─ upper arm ─ J3 elbow ─ forearm ─ J4 roll
//    ─ wrist DIFFERENTIAL (J5 pitch + J6 roll) ─ GRIPPER
//
//  Colors: gray=structure, green=joint drums/sectors, blue=motors,
//          orange=idlers/differential, red=cord-bundle hint.
//  Cords are only HINTED (red) — real routing is the stacked idler
//  trunk described in turntable_spec.md.
// ============================================================

$fn = 64;

// ---- link lengths (mm) ----
H_mast = 70;     // turntable top -> J2 axis
a1 = 200;        // upper arm  (J2 -> J3)
a2 = 200;        // forearm    (J3 -> J4/wrist)
a3 = 90;         // wrist      (J5 -> tool)
tube_od = 40;

// ---- pose (deg) ----
q1 = 25;   // base yaw
q2 = 35;   // shoulder
q3 = -62;  // elbow
q4 = 15;   // forearm roll
q5 = 40;   // wrist pitch
q6 = 0;    // tool roll
grip = 16; // gripper opening

// ---------- primitives ----------
module nema(h=40){ color("steelblue") translate([-21,-21,0]) cube([42,42,h]); }

module link(L, od){
    color("gainsboro") difference(){
        cylinder(h=L, d=od);
        translate([0,0,-1]) cylinder(h=L+2, d=od-6);
    }
    color("indianred") cylinder(h=L, d=3);        // cord-bundle hint
}
module drum_pitch(d){ color("seagreen") rotate([90,0,0]) cylinder(h=20, d=d, center=true); }
module drum_roll(d){  color("seagreen") cylinder(h=20, d=d, center=true); }
module idler_stack(grv=8){
    for(i=[0:grv-1]) color("orange")
        rotate([90,0,0]) translate([0,0,i*2.4-grv*1.2]) cylinder(h=1.8, d=22);
}

module base(){
    color([0.3,0.3,0.32]) cylinder(h=40, d=130);
}
module turntable(){
    color("gainsboro") cylinder(h=8, d=210);
    for(i=[0:5]){ a=i*60;
        translate([80*cos(a),80*sin(a),8]) rotate([0,0,a]) nema(); }
    color([0.7,0.7,0.72]) translate([0,0,8]) cylinder(h=H_mast, d=46);  // shoulder mast
}
module differential(){
    for(s=[-1,1]) translate([0,s*22,0]) rotate([90,0,0])    // side pulleys on pitch(Y)
        color("orange") cylinder(h=8, d=30, center=true);
    color("seagreen") cylinder(h=42, d=26);                  // roll output along Z (tool)
    color([0.7,0.7,0.7]) translate([0,-26,0]) cube([16,52,16], center=true); // carrier yoke
}
module gripper(g){
    color("dimgray") cylinder(h=12, d=30);
    for(s=[-1,1]) translate([s*7,0,12]) rotate([0,s*g,0])
        color([0.4,0.4,0.45]) translate([-2.5,-4,0]) cube([5,8,42]);
}

// ---------- kinematic chain ----------
module arm(){
    base();
    translate([0,0,40]) rotate([0,0,q1]){          // J1 base yaw
        turntable();
        translate([0,0,8+H_mast]) rotate([0,q2,0]){ // J2 shoulder (pitch)
            drum_pitch(120); idler_stack(10);
            link(a1, tube_od);
            translate([0,0,a1]) rotate([0,q3,0]){    // J3 elbow (pitch)
                drum_pitch(110); idler_stack(8);
                link(a2, 38);
                translate([0,0,a2]) rotate([0,0,q4]){ // J4 forearm roll
                    drum_roll(64);
                    translate([0,0,28]) rotate([0,q5,0]){ // J5 wrist pitch
                        differential();
                        link(a3, 24);                         // wrist -> tool tube
                        translate([0,0,a3]) rotate([0,0,q6]) // J6 tool roll
                            gripper(grip);
                    }
                }
            }
        }
    }
}

arm();

echo(str("Reach from shoulder = ", a1+a2+a3, " mm ; shoulder height ~ ",
         40+8+H_mast, " mm ; max tip height ~ ", 40+8+H_mast+a1+a2+a3, " mm"));

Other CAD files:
parked/arm_link.scad
cycloid_joint.scad
legacy/arm_section.scad
legacy/cycloid_joint.scad
parked/arm_v1.scad
parked/base.scad
parked/belt_stage.scad
parked/bldc_2204.scad
parked/cable_wrist.scad
parked/capstan.scad
parked/capstan_drive.scad
parked/capstan_teststand.scad
parked/coaxial_joint.scad
parked/cycloidal_disc.scad
parked/harmonic_ring.scad
parked/integrated_actuator.scad
parked/joint_module.scad
parked/turntable.scad
parked/whole_arm.scad
parked/wrist_differential.scad

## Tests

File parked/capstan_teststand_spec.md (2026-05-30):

# Remote capstan test stand — build & test

Purpose: measure whether Dyneema routed **over idlers** ("remote" capstan)
transmits force with ~zero backlash, vs the adjacent capstan→pulley
baseline. Decides the whole arm's cable architecture. File:
`capstan_teststand.scad`.

## Layout
```
 [NEMA17 under plate → helical capstan DRUM (r=8)]
        │ 2 cable runs (pull-pull), Dyneema DM20
        ▼ over
 [2 idler 608s in clevises]  ← position-adjustable (turn angle = the variable)
        │
 [DRIVEN PULLEY r=48 (6:1) + magnet/encoder + load arm]
```

## Idler load — why 608, double-supported
Cable turning angle θ over an idler → bearing radial load **F = 2·T·sin(θ/2)**.
At a J2-class run tension T ≈ 260 N (80 N pretension + ~183 N load):
| θ | F_idler |
|---|---|
| 30° | 135 N |
| 60° | 260 N |
| 90° | 370 N |
| 180° | 520 N |
- **608** static rating ~1.4 kN → comfortable even at 90°. (A 623 ~180 N
  static would fail — do not use small bearings here.)
- **Shaft in double shear** (clevis, both arms) — never a cantilevered
  shoulder screw at these loads.
- **Design lever:** keep turn angles small (two gentle idlers beat one
  sharp one). The slots let you vary θ and watch the load/friction.
- 608 radius 11 mm = 11× cord dia → also good for Dyneema bend life.

## BOM
| Qty | Item |
|----:|---|
| 1 | NEMA17 stepper + driver (TMC2209 / any) |
| 1 | printed capstan drum (helical groove, anchor hole) |
| 1 | printed driven pulley (groove, 2 anchors, magnet pocket, load arm) |
| 1 | printed pulley post + 2× 608 (driven shaft) |
| 2 | idler clevis + 608 + 8 mm shaft (ground rod) + retainers |
| 1 | AS5600 board + 6×2.5 mm diametric magnet |
| 1 | MCU (read AS5600 over I²C, step the motor) |
| — | Dyneema DM20, splice tools / crimp ferrules |
| 1 | constant-force spring (or screw tensioner) |
| — | M3 heat-set inserts + screws; baseplate (printed or ply/alu) |
| — | hook weights (load arm) |

## Lacing the cable (pull-pull, no slip)
1. Anchor cord mid-drum (anchor hole), lay ~6–8 helical wraps.
2. Take both ends off the drum, run each to the pulley **over its own
   idler** (one run per idler, or both over a wide idler).
3. Splice/clamp each end into the pulley's two anchor channels, on
   opposite sides, so winding one run unwinds the other.
4. One end terminates on the **constant-force spring** → sets pretension,
   absorbs Dyneema creep. Pre-stretch the cord first.
5. **No knots** — splice or ferrule.

## Test procedure
**A. Backlash (the headline number)**
- Power the motor holding (or lock the drum). Apply a small ± torque at
  the load arm; read the AS5600 deflection. That angle = backlash +
  compliance. Target: **< ~0.3°** referred to the output.
- **Baseline:** remove idlers, move pulley adjacent to the drum (direct
  capstan), repeat. The *difference* is the idlers' contribution — the
  whole point of the test.

**B. Friction / efficiency**
- Hang known weights on the load arm (torque = W·arm). Note motor current
  / steps to lift vs lower. Compare with/without idlers and at different
  idler turn angles.

**C. Creep & tension hold**
- Tension, run 100s of cycles, re-measure backlash and pretension over
  time. Confirm the constant-force spring holds it (no slack return).

**D. Idler load sanity**
- At max test tension, check idler shaft deflection / bearing feel and
  that the clevis isn't flexing. Vary θ via the slots; watch friction rise
  with angle.

## Targets (go/no-go for the arm)
- Backlash (remote) < ~0.3°, and not dramatically worse than baseline.
- No cord slip (anchored → should be zero).
- Pretension holds over cycling (spring works).
- Idler friction acceptable at the turn angles the arm will actually use.

If remote-capstan backlash ≈ baseline → the architecture is proven, scale
to a real joint (Proto on the crossed-roller bearing). If idlers add
significant lash/friction → reconsider turn angles or fall back to
adjacent capstans per joint.

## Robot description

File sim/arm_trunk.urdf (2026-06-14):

<?xml version="1.0"?>
<!-- GENERATED by arm_assembly.py - do not hand-edit. -->
<!-- 5-DOF micro-cyclo arm: every joint 20:1 Micro except the base
     slew. upper_arm + forearm links ARE the printed arm sections
     (meshes/arm_long.stl); base + wrist 90deg sections are stand-ins. -->
<robot name="micro_arm">
  <mujoco><compiler balanceinertia="true" discardvisual="false" fusestatic="false" meshdir="meshes"/></mujoco>
  <material name="motor"><color rgba="0.13 0.13 0.15 1"/></material>
  <material name="link"> <color rgba="0.78 0.78 0.80 1"/></material>
  <material name="tool"> <color rgba="0.27 0.51 0.71 1"/></material>
  <link name="base_link">
    <visual><origin xyz="0 0 0.038" rpy="0 0 0"/><geometry><mesh filename="cyclo_cage.stl" scale="0.001 0.001 0.001"/></geometry><material name="link"/></visual>
    <inertial><origin xyz="0.0000 0.0000 0.0200"/><mass value="0.5000"/><inertia ixx="2.96e-04" iyy="2.96e-04" izz="4.08e-04" ixy="0" ixz="0" iyz="0"/></inertial>
  </link>

  <joint name="j1_yaw" type="revolute">
    <parent link="base_link"/><child link="mast_link"/>
    <origin xyz="0.0000 0.0000 0.0470"/><axis xyz="0 0 1"/>
    <limit lower="-3.1416" upper="3.1416" effort="3.6" velocity="3.0"/>
    <dynamics damping="0.05"/>
  </joint>

  <link name="mast_link">
    <visual><origin xyz="0 0 0" rpy="0 0 1.570796325"/><geometry><mesh filename="angle_mount.stl" scale="0.001 0.001 0.001"/></geometry><material name="link"/></visual>
    <inertial><origin xyz="0.0000 -0.0150 0.0300"/><mass value="0.4530"/><inertia ixx="2.79e-04" iyy="2.79e-04" izz="2.70e-04" ixy="0" ixz="0" iyz="0"/></inertial>
  </link>

  <joint name="j2_shoulder" type="revolute">
    <parent link="mast_link"/><child link="upper_arm_link"/>
    <origin xyz="0.0000 0.0360 0.0420"/><axis xyz="0 1 0"/>
    <limit lower="-1.9200" upper="1.9200" effort="5.5" velocity="3.0"/>
    <dynamics damping="0.05"/>
  </joint>

  <link name="upper_arm_link">
    <visual><origin xyz="0 0 0" rpy="0 0 0"/><geometry><mesh filename="arm_upper.stl" scale="0.001 0.001 0.001"/></geometry><material name="link"/></visual>
    <inertial><origin xyz="0.0736 -0.0046 0.0000"/><mass value="0.3004"/><inertia ixx="7.09e-05" iyy="4.29e-04" izz="3.75e-04" ixy="0" ixz="0" iyz="0"/></inertial>
  </link>

  <joint name="j3_elbow" type="revolute">
    <parent link="upper_arm_link"/><child link="forearm_link"/>
    <origin xyz="0.0750 -0.0046 0.0000"/><axis xyz="0 1 0"/>
    <limit lower="-2.6200" upper="2.6200" effort="3.6" velocity="3.0"/>
    <dynamics damping="0.05"/>
  </joint>

  <link name="forearm_link">
    <visual><origin xyz="0 0 0" rpy="0 0 0"/><geometry><mesh filename="arm_fore.stl" scale="0.001 0.001 0.001"/></geometry><material name="link"/></visual>
    <inertial><origin xyz="0.0512 -0.0046 0.0000"/><mass value="0.1933"/><inertia ixx="4.56e-05" iyy="1.95e-04" izz="1.60e-04" ixy="0" ixz="0" iyz="0"/></inertial>
  </link>

  <joint name="j4_wrist_pitch" type="revolute">
    <parent link="forearm_link"/><child link="wrist_link"/>
    <origin xyz="0.0520 -0.0046 0.0000"/><axis xyz="0 1 0"/>
    <limit lower="-1.9200" upper="1.9200" effort="1.32" velocity="3.0"/>
    <dynamics damping="0.03"/>
  </joint>

  <link name="wrist_link">
    <visual><origin xyz="0 0 0" rpy="-1.570796325 0 0"/><geometry><mesh filename="angle_mount.stl" scale="0.001 0.001 0.001"/></geometry><material name="link"/></visual>
    <inertial><origin xyz="0.0200 -0.0060 0.0000"/><mass value="0.2180"/><inertia ixx="9.17e-05" iyy="9.17e-05" izz="9.17e-05" ixy="0" ixz="0" iyz="0"/></inertial>
  </link>

  <joint name="j5_tool_roll" type="revolute">
    <parent link="wrist_link"/><child link="tool_link"/>
    <origin xyz="0.0380 0.0420 0.0000"/><axis xyz="1 0 0"/>
    <limit lower="-3.1416" upper="3.1416" effort="1.32" velocity="3.0"/>
    <dynamics damping="0.03"/>
  </joint>

  <link name="tool_link">
    <visual><origin xyz="0.006 0 0" rpy="0 1.5708 0"/><geometry><cylinder radius="0.018" length="0.006"/></geometry><material name="link"/></visual>
    <visual><origin xyz="0.022 0 0"/><geometry><box size="0.022 0.05 0.026"/></geometry><material name="link"/></visual>
    <visual><origin xyz="0.05 0.019 0"/><geometry><box size="0.05 0.008 0.024"/></geometry><material name="tool"/></visual>
    <visual><origin xyz="0.05 -0.019 0"/><geometry><box size="0.05 0.008 0.024"/></geometry><material name="tool"/></visual>
    <inertial><origin xyz="0.0300 0.0000 0.0000"/><mass value="0.2800"/><inertia ixx="7.47e-05" iyy="1.21e-04" izz="1.21e-04" ixy="0" ixz="0" iyz="0"/></inertial>
  </link>

  <joint name="tcp_fixed" type="fixed"><parent link="tool_link"/><child link="tcp_link"/><origin xyz="0.08 0 0"/></joint>
  <link name="tcp_link"><inertial><mass value="0.001"/><inertia ixx="1e-6" iyy="1e-6" izz="1e-6" ixy="0" ixz="0" iyz="0"/></inertial></link>
  <transmission name="tr_j1_yaw"><type>transmission_interface/SimpleTransmission</type>
    <joint name="j1_yaw"><hardwareInterface>hardware_interface/PositionJointInterface</hardwareInterface></joint>
    <actuator name="j1_yaw_act"><mechanicalReduction>20</mechanicalReduction></actuator></transmission>

  <transmission name="tr_j2_shoulder"><type>transmission_interface/SimpleTransmission</type>
    <joint name="j2_shoulder"><hardwareInterface>hardware_interface/PositionJointInterface</hardwareInterface></joint>
    <actuator name="j2_shoulder_act"><mechanicalReduction>20</mechanicalReduction></actuator></transmission>

  <transmission name="tr_j3_elbow"><type>transmission_interface/SimpleTransmission</type>
    <joint name="j3_elbow"><hardwareInterface>hardware_interface/PositionJointInterface</hardwareInterface></joint>
    <actuator name="j3_elbow_act"><mechanicalReduction>20</mechanicalReduction></actuator></transmission>

  <transmission name="tr_j4_wrist_pitch"><type>transmission_interface/SimpleTransmission</type>
    <joint name="j4_wrist_pitch"><hardwareInterface>hardware_interface/PositionJointInterface</hardwareInterface></joint>
    <actuator name="j4_wrist_pitch_act"><mechanicalReduction>20</mechanicalReduction></actuator></transmission>

  <transmission name="tr_j5_tool_roll"><type>transmission_interface/SimpleTransmission</type>
    <joint name="j5_tool_roll"><hardwareInterface>hardware_interface/PositionJointInterface</hardwareInterface></joint>
    <actuator name="j5_tool_roll_act"><mechanicalReduction>20</mechanicalReduction></actuator></transmission>

</robot>

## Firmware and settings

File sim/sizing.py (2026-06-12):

#!/usr/bin/env python3
"""
sizing.py — weight & torque analysis for the cycloid arm.

Answers: "how long can the members be?" and "which motor?" The limit is the
gravity moment at the shoulder (J2): it must HOLD everything beyond it at full
horizontal extension. Heavy motors out near the wrist hurt twice — their own
weight loads the shoulder. We build a lumped-mass model, use MuJoCo inverse
dynamics for the required holding torque, and compare to what each motor (on
the printed cycloidal) can deliver continuously.

    pip install mujoco
    python sim/sizing.py

KEY PRINCIPLE the catalog encodes: the *reduction* should come from the printed
cycloidal (light, ~0 backlash), NOT a metal planetary gearbox (~250-300 g).
So the motor should be BARE and light. Torque scaling:
  * stepper torque ~ stack LENGTH  -> a "pancake" stepper is just weaker, same
    torque/gram. Not a win.
  * BLDC outrunner torque ~ radius^2 -> a flat, wide pancake outrunner is the
    torque-dense flat motor. That's the real lever (needs FOC + encoder).
All numbers are editable estimates — plug in datasheet values to sharpen.
"""
import mujoco, numpy as np

g = 9.81

# ---------------- the printed reduction (shared) ----------------
RATIO = 20          # cycloidal reduction
EFF   = 0.70        # cycloidal efficiency (printed, conservative)
CONT  = 0.60        # stepper usable continuous fraction (thermal); BLDC similar
CYCLO_PRINTED = 0.05  # printed MICRO cyclo stage per joint (body+plates+bearings), kg

# ---------------- MOTOR CATALOG ----------------
# name: dict(t=continuous torque at the MOTOR shaft [N*m], m=bare motor mass [kg],
#            kind, note). 'geared' kind already includes its gearbox (t=output, no cyclo).
MOTORS = {
 "NEMA8 stepper":      dict(t=0.015, m=0.060, kind="step", note="tiny, weak"),
 "NEMA11 stepper":     dict(t=0.060, m=0.095, kind="step", note="bare, simple"),
 "NEMA14 stepper":     dict(t=0.120, m=0.140, kind="step", note="bare"),
 "NEMA17 stepper":     dict(t=0.260, m=0.300, kind="step", note="cont=0.6x0.44 hold"),
 "geared NEMA14 19:1": dict(t=1.68,  m=0.411, kind="geared", note="metal gearbox; 1deg backlash"),
 "gimbal BLDC GBM2804":dict(t=0.030, m=0.055, kind="bldc", note="FOC+enc; torque-weak"),
 "gimbal BLDC GBM4108":dict(t=0.080, m=0.110, kind="bldc", note="FOC+enc"),
 "pancake BLDC 5208":  dict(t=0.180, m=0.175, kind="bldc", note="FOC+enc; flat outrunner"),
 "pancake BLDC 8108":  dict(t=0.350, m=0.230, kind="bldc", note="FOC+enc; flat, torque-dense"),
}

def joint_out_cont(mo, ratio=RATIO):
    """Continuous output torque at the JOINT for a motor at a given reduction.
    'geared' motors carry their own fixed gearbox (ratio arg ignored)."""
    if mo["kind"] == "geared":
        return mo["t"] * CONT
    return mo["t"] * ratio * EFF * CONT

def joint_mass(mo):
    """Mass of the whole joint actuator (motor + printed cyclo, or geared as-is)."""
    return mo["m"] if mo["kind"] == "geared" else mo["m"] + CYCLO_PRINTED

# ---------------- lumped-mass arm ----------------
M_OUTBODY = 0.04    # printed micro output body at each joint (small lever, proximal)
PAYLOAD   = 0.25
M_TOOL    = 0.03
RHO_PLA   = 700.0; MEM_W, MEM_T = 0.036, 0.005   # the flat blade (ARM_Z x ARM_T)
def member_mass(L): return RHO_PLA * MEM_W * MEM_T * L
H_SH = 0.12
L1d, L2d, L3, L4 = 0.150, 0.150, 0.050, 0.078   # default member lengths


def build(L1, L2, m_elbow, m_wrist=None, payload=PAYLOAD):
    """Planar chain. m_elbow = J3 (elbow) actuator mass; m_wrist = J4/J5 wrist
    actuator mass (defaults to m_elbow). Each actuator sits at the DISTAL joint
    of its link (worst lever); each link also has its member + output body."""
    if m_wrist is None: m_wrist = m_elbow
    m_ua = M_OUTBODY + member_mass(L1) + m_elbow
    c_ua = (member_mass(L1)*L1/2 + m_elbow*L1) / m_ua
    m_fa = M_OUTBODY + member_mass(L2) + m_wrist
    c_fa = (member_mass(L2)*L2/2 + m_wrist*L2) / m_fa
    m_wr = m_wrist + 0.02
    m_to = M_TOOL + payload
    def I(m): return max(m*4e-4, 1e-5)
    return f"""
<mujoco><option gravity="0 0 -{g}"/><worldbody>
 <body name="ua" pos="0 0 {H_SH}"><joint type="hinge" axis="0 1 0"/>
  <inertial pos="0 0 {c_ua}" mass="{m_ua}" diaginertia="{I(m_ua)} {I(m_ua)} {I(m_ua)}"/>
  <body name="fa" pos="0 0 {L1}"><joint type="hinge" axis="0 1 0"/>
   <inertial pos="0 0 {c_fa}" mass="{m_fa}" diaginertia="{I(m_fa)} {I(m_fa)} {I(m_fa)}"/>
   <body name="wr" pos="0 0 {L2}"><joint type="hinge" axis="0 1 0"/>
    <inertial pos="0 0 {L3/2}" mass="{m_wr}" diaginertia="{I(m_wr)} {I(m_wr)} {I(m_wr)}"/>
    <body name="to" pos="0 0 {L3}"><joint type="hinge" axis="0 0 1"/>
     <inertial pos="0 0 {L4}" mass="{m_to}" diaginertia="{I(m_to)} {I(m_to)} {I(m_to)}"/>
    </body></body></body></body></worldbody></mujoco>"""


def j2_demand(L1, L2, m_elbow, m_wrist=None, **kw):
    m = mujoco.MjModel.from_xml_string(build(L1, L2, m_elbow, m_wrist, **kw))
    d = mujoco.MjData(m); d.qpos[:] = [np.pi/2, 0, 0, 0]
    mujoco.mj_inverse(m, d)
    return abs(d.qfrc_inverse[0])

def max_member(out_cont, m_act):
    """Largest equal member length (L1=L2=L) within continuous shoulder torque."""
    best = 0
    for L in range(50, 421, 5):
        if j2_demand(L/1000, L/1000, m_act) <= out_cont: best = L
    return best


def catalog():
    print("="*96)
    print("MOTOR CATALOG — same motor at every joint, on the printed cycloidal.")
    print("max member = longest equal limbs the SHOULDER can hold continuously, at 20:1 vs 36:1.")
    print("="*96)
    print(f"{'motor':<22}{'joint':>7}{'wrist pr':>9}{'mem@20:1':>10}{'mem@36:1':>10}  note")
    print("-"*96)
    for name, mo in MOTORS.items():
        jm = joint_mass(mo)
        m20 = max_member(joint_out_cont(mo, 20), jm)
        m36 = max_member(joint_out_cont(mo, 36), jm)
        f20 = f"{m20}mm" if m20 else "TOO WEAK"
        f36 = f"{m36}mm" if m36 else "TOO WEAK"
        print(f"{name:<22}{jm*1000:6.0f}g{2*jm*1000:8.0f}g{f20:>10}{f36:>10}  {mo['note']}")
    print("-"*96)
    print(f"payload {PAYLOAD*1000:.0f}g | reach = 2*member + {1000*(L3+L4):.0f}mm wrist/tool. "
          f"36:1 = your belt pre-stage. geared NEMA14 fixed at 19:1 (can't add reduction).")


def mixed():
    print("\n" + "="*96)
    print("RECOMMENDED MIXED BUILD — torque-dense where it lifts, lightest where it hangs")
    print("="*96)
    # different motor per role: shoulder/elbow carry load; wrist just needs to be light
    for sh_name, sh_ratio in [("NEMA17 stepper", 36), ("pancake BLDC 8108", 36)]:
        sh = MOTORS[sh_name]; wmo = MOTORS["gimbal BLDC GBM2804"]
        oc = joint_out_cont(sh, sh_ratio)
        # elbow motor mass = shoulder-class; wrist motors = light gimbal
        m_elbow = joint_mass(sh); m_wrist = joint_mass(wmo)
        best = 0
        for L in range(50, 421, 5):
            if j2_demand(L/1000, L/1000, m_elbow, m_wrist) <= oc: best = L
        print(f"  shoulder/elbow {sh_name} @{sh_ratio}:1 (out {oc:.1f}Nm) + wrist gimbal 2804 "
              f"({m_wrist*1000:.0f}g) -> {best}mm members, reach ~{(2*best)/1000+L3+L4:.2f}m")
    print("  all reduction from printed cycloidal (~0 backlash). BLDC cost: FOC+encoder x5.")


if __name__ == "__main__":
    catalog()
    mixed()

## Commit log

2026-05-30 Initial design: 3D-printed cable-driven robot arm
    6-DOF (5-DOF fallback) arm built around remote Dyneema capstan drives:
    low backlash, light links, NEMA17 motors kept off the arm. Includes the
    full design rationale (DESIGN.md), wrist-mechanism trade study, parametric
    OpenSCAD CAD (capstan sizer, test stand, joints, whole-arm viz), and the
    gear-based exploratory fallback files.
    [arm_assembly.scad, arm_link.scad, belt_stage.scad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]
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2026-05-31 Add base (moment-bearing carrier + 4:1 internal-ring J1) and v1 build config
    [base.scad]
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2026-05-31 Add arm_v1 top-level assembly render (cycloid joints + bevel-diff wrist, 5-DOF)
    Reflects the converged v1 build config; supersedes the cable-concept render
    for the canonical whole-arm view.
    [arm_v1.scad]
2026-06-01 Add 2204 BLDC model + motor-options comparison; expand parked-BLDC analysis
    - bldc_2204.scad: parametric fit/envelope model of a 2204-class outrunner
    - bldc_2204.png: overview render
    - bldc_options.md: KV-market breakdown + 10-candidate comparison table;
    the KV<->reduction trade and holding-current-at-stall analysis
    - DESIGN.md: small-frame-BLDC-as-NEMA17-drop-in sub-idea (torque math,
    mass win, 3 catches, gimbal-wind recommendation); file-index entry
    [bldc_2204.scad]
2026-06-01 Add integrated BLDC-cycloidal actuator concept (frameless motor in reducer)
    - integrated_actuator.scad: parametric concept cross-section — rotor magnet
    ring as eccentric carrier, fixed stator+pin ring, output on moment bearing
    - integrated_actuator.png: half-section render of the stack
    - DESIGN.md: integrated-actuator idea (member mapping, axial stack, the 4
    integration challenges: air-gap concentricity, heat path, dual encoders,
    balance; outrunner-vs-inrunner and cycloidal-vs-harmonic forks)
    - DESIGN.md: add Skyentific to references (printed BLDC-cycloidal actuators);
    file-index entries for bldc_options.md + integrated_actuator.scad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
    [integrated_actuator.scad]
2026-06-01 Pare down to buildable 3-DOF cycloid trunk; consolidate joint; park explorations
    Converged scope: J1/J2/J3 are ONE parametric cycloidal cartridge at three
    sizes. J1 = the cartridge stood vertical, its output bearing sized up = the
    moment bearing (no separate base mechanism).
    - cycloid_joint.scad: NEW canonical joint. Merges cycloidal_disc (profile
    math) + joint_module (cam/flange) + coaxial_joint (stator/rotor cartridge,
    bearing outboard) + base. Presets cfg(J1/J2/J3); part/which render selects.
    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
    [arm_assembly.scad, arm_link.scad, arm_trunk.scad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]
2026-06-09 Add MuJoCo sim scaffold (3-DOF trunk URDF + viewer) and Sweep Micro BOM
    sim/arm_trunk.urdf: 3-DOF cycloid trunk as a kinematic model (primitive
    geometry, meters), joints/links mirror arm_trunk.scad. Verified in MuJoCo:
    compiles clean, straight-up tip 0.604 m, shoulder-out radial reach 0.486 m.
    sim/view.py: load + pose in the interactive viewer.
    parked/sweep_micro_bom.md: hardware list for the Sweep 20:1 Micro reference
    drive (bearings + nylon output rollers), sourcing resolved.
    [arm_trunk.urdf]
2026-06-09 Make MuJoCo poser interactive: working sliders + keyboard, add sweep demo
    view.py: add position-servo actuators via MjSpec so the Control-tab sliders
    appear; loop mirrors data.ctrl onto qpos instead of overwriting it each frame
    (fixes slider snap-back/flicker). Keyboard fallback (Q/A W/S E/D, R reset) for
    native-Wayland setups where MuJoCo's bundled GLFW won't take UI slider drags.
    sweep.py: animated workspace demo (no UI interaction) + --pose for static holds.
2026-06-09 Use real Cycloidal R20 drive mesh at each joint in the sim
    Converted Assy_Cycloid_R20_v0.STEP (ratio-20 cycloidal drive, 63.5mm sq x
    57.4mm) to a recentered binary STL (axis=Z, base=z0, ~73k tris) via gmsh,
    and swapped the placeholder joint cylinders in arm_trunk.urdf for this mesh
    (one asset instanced 3x, scaled mm->m, oriented to each joint axis).
    Per-part STLs in the package are print-oriented, so the STEP assembly is the
    only source of true relative positions. Visual only; inertials unchanged.
    [arm_trunk.urdf]
2026-06-10 Mechanically faithful R20 joints: split drive, real motor, flat members
    - Split the R20 STEP into FIXED half (motor plate + the real stepper, which
    is shell geometry in the STEP, + screws) and OUTPUT body (rotating ring
    wheels). Each joint straddles the revolute joint: motor mesh on the parent
    link, body mesh on the child -> the round output body rotates against the
    fixed motor like the real actuator.
    - Drives centered on the joint so the two segments bolt to opposite ends and
    are offset ~36 mm; J2/J3 alternate side (+Y/-Y) so the arm zig-zags and
    segments clear. Round mounting plates match the round output face.
    - Arm segments modeled as flat plate members. Real stepper now visi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
    [arm_trunk.urdf]
2026-06-10 Extend to 5-DOF: add wrist-pitch + tool-roll on 20:1 Micro cycloidal
    Chain: J1 yaw, J2 shoulder-pitch, J3 elbow-pitch (R20), J4 wrist-pitch and
    J5 tool-roll (Sweep 20:1 Micro). Dropped the forearm-roll (avoids roll
    redundancy; pitch-then-tool-roll wrist as discussed).
    - micro20.stl: Micro 20:1 drive from its STEP (internal ladder discs dropped
    to keep it light, ~21k tris). Single mesh, mounted on the parent (fixed)
    side at each wrist joint; child link articulates.
    - view.py: keyboard now covers all joints (Q/A W/S E/D R/F T/G, X=reset);
    loop/readout generalized to model.nu.
    Reach ~0.49 m preserved; all 5 joints verified controllable in the viewer.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
    [arm_trunk.urdf]
2026-06-10 Add weight & torque sizing analysis with motor catalog
    sizing.py: lumped-mass arm + MuJoCo inverse dynamics to find the shoulder
    holding torque at worst case, and the max member length each motor can hold
    continuously on the printed cycloidal. Key results:
    - Shoulder (J2) is the binding joint; heavy motors at the wrist hurt twice.
    - Reduction is the dominant lever: 20:1 holds almost nothing continuously;
    36:1 (your belt pre-stage) roughly doubles reach.
    - Geared steppers lose: the metal planetary is ~300g; build reduction in the
    printed cyclo instead and keep the motor bare.
    - 'Pancake' helps only as a BLDC OUTRUNNER (torque ~ radius^2); pancake
    steppers and gimbal BLDCs are torque-wea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
    [sizing.py]
2026-06-10 Add gravity dynamics view (force-limited servos, real masses)
    gravity.py: steps real physics instead of kinematic posing. Gravity on,
    realistic link masses (actuators+members+payload) set via MjSpec, and each
    joint is a position servo whose force is CLAMPED to the actuator's real output
    torque -> the arm holds or visibly sags exactly like the real thing. Live
    console readout shows per-joint torque and flags any joint over its continuous
    (thermal) limit. Per-joint servo gains are scaled to each joint's inertia
    (uniform bandwidth) so the near-zero-inertia wrist-roll joint stays stable;
    implicitfast integrator. Confirms the sizing result: NEMA17+R20 build holds a
    horizontal-extended pose only a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
2026-06-10 Add backlash -> tool-tip error budget
    backlash.py: per-joint backlash spec (BACKLASH_DEG) -> worst-case tool-tip
    slop, using the MuJoCo translational Jacobian as each joint's lever arm to the
    TCP. Shows base joints (J1/J2, longest lever) dominate the budget while the
    tool-roll joint contributes ~0, and quantifies why low-backlash cycloidal
    (~0.1-0.2deg, ~2-5mm) beats a planetary geared stepper (~1deg, ~24mm tip slop).
    Editable specs + drive-type comparison.
2026-06-10 Record reduction via URDF transmissions; model non-backdrivability
    - arm_trunk.urdf: add ROS <transmission> blocks (SimpleTransmission,
    mechanicalReduction=20) recording each joint's cycloidal reduction. ros2_control
    reads these; MuJoCo ignores them (gets actuators from the sim scripts), and the
    URDF still loads clean.
    - gravity.py: add per-joint frictionloss = Coulomb friction reflected to the
    joint output, modeling the NON-BACKDRIVABILITY of a high-reduction cyclo+stepper.
    Cuts back-driven shoulder deflection ~2x in a reaction test. Set FRICTION=0 to
    feel a free-pivot. (Backlash dead-band is still un-modeled; backlash.py covers
    the static tip-error budget separately.)
    Co-Aut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
    [arm_trunk.urdf]
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2026-06-10 Add G-code path mode (drawing/dispensing) + continuous path follower
    - control.py: trace_path() follows a continuous Cartesian polyline at per-segment
    speed without stopping at waypoints (smooth path tracing). Removed the unused
    lead_limit param.
    - gcode.py: parse G0/G1 X Y Z F (+ G20/21, G90/91, comments), map the G-code frame
    onto a work plane in the robot's reach, and stream it through the closed-loop
    controller so the tool tip traces the path. Built-in demo (square + circle);
    runs a .gcode file; --check reports drawing-line tracking error (~0.7mm mean,
    3mm at sharp corners). Z = pen height (Z>0 lifts off the plane).
2026-06-10 Add collision-aware motion planner (pick-and-place autonomy mode)
    - plan.py: RRT-Connect motion planner with MuJoCo collision checking. Builds a
    planning scene (simple capsule collision geom per link + world boxes for the
    object/obstacle, adjacent-link exclusions, visual meshes set non-colliding),
    solves IK to a grasp pose, and finds a collision-free joint path avoiding world
    obstacles AND self-collision. Verified: blocked direct path -> RRT detours,
    0 colliding states along the result. Object poses in OBJECTS are the perception/
    LLM seam. Correct grasp model: gripper may contact its target object, nothing
    else may.
    - control.py: add IKController.solve_ik (absolute kinematic IK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
2026-06-10 DESIGN: capture actuator findings from simulation (§0.5), refresh decisions
    Bridge the sim work to the actuator iteration: new §0.5 'Actuator findings from
    simulation' records the quantified conclusions (shoulder is the binding joint;
    reduction is the dominant reach lever; geared steppers lose to bare-motor +
    printed cyclo; pancake helps only as a BLDC outrunner; wrist mass dominates;
    backlash budget dominated by base joints; cycloidal 2-5mm vs planetary ~24mm tip
    slop). Marks the cable-era §10 torque budget superseded; refreshes §12 open
    decisions around the active actuator selection. Re-run sim/sizing.py as motors
    change.
2026-06-12 Prep for public release: integrated-actuator arm section, layout cleanup, licensing
    - Add arm_section.scad: the integrated-actuator arm link (Sweep micro cyclo
    body + NEMA17 plate fused into one printable section), parametric per PART.
    - Vendor geometry: track ONLY the two derivative-input parts (micro body +
    NEMA17 plate) under vendor/ with attribution; everything else .gitignored
    and user-supplied from purchase.
    - Remove vendor-derived sim meshes from the tree (user-supplied; history
    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
    [arm_section.scad]
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2026-06-12 arm_section: arm is the plate extended (flat blade), flush both ends
    Per inspection of the STEP: make the arm the NEMA mount-plate extended to the
    body (ARM_T = plate edge = 9mm, coplanar/centered), tall in Z for sag stiffness.
    Fixes the ~1mm-proud body end (arm+saddle now within the 18.2mm body width) and
    keeps the mount-plate edge clear of the arm. Drops the old tall beam + gusset;
    adds a flush body saddle to fair the blade into the round body.
    [arm_section.scad, arm_trunk.scad, cycloid_joint.scad]
2026-06-12 Deprecate OpenSCAD: build123d is the CAD toolchain
    Move arm_section/cycloid_joint/arm_trunk .scad to legacy/ (kept for reference,
    not maintained); add legacy/README. Fix legacy/arm_section.scad vendor path.
    README + DESIGN: build123d (arm_section.py) is the build CAD; .scad deprecated.
    [arm_section.scad]
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2026-06-12 arm_section: center both actuators on the arm axis; arm ends at plate edge
    Final long-section geometry: both actuator centers sit on the same line (the
    arm axial center, Z=0) -- the distal plate is no longer hung/offset. The arm
    blade is shortened to end coincident with the plate's near edge (small weld
    overlap) so it never covers the plate face, leaving the central boss fully clear
    for the next joint to mount.
2026-06-12 arm_section: test-print geometry — 5mm arm, half length, flat-print aligned
    - Arm thinned to 4.9mm (the NEMA plate-flange thickness) so it clears the next
    actuator; SEG_LEN halved to 75mm for a quick test print.
    - Flat-print alignment: arm sits flush with the body's -Y face and the plate
    shares that plane, so the section has one flat bed face (axes stay at Z=0).
    - Plate flipped (Rot about X) so the flange is the flat face and the boss faces
    up where the next joint mounts.
2026-06-12 arm_section: radius the arm's body end to clear the disc cavity
    The arm's flat proximal end reached the bore wall near the body center, fouling
    the rotating internals. Carve the end to the body clearance circle (CLEAR_R =
    bore + 2mm) by subtracting a Y-axis cylinder, so the arm wraps the body OD and
    the disc cavity stays fully clear.
2026-06-12 sim: rebuild the MuJoCo arm around the integrated arm sections
    - arm_trunk.urdf is now the 5-DOF micro-cyclo arm: every joint a 20:1 Micro
    except the base slew. The upper-arm + forearm links ARE the real printed
    sections (meshes/arm_long.stl from arm_section.py) -- the section mesh carries
    its own housing/plate end pieces. Base + wrist 90deg sections are stand-ins.
    - sim/gen_meshes.py: one command to export the section meshes from the build123d
    CAD (gitignored, vendor-derived). sim/README updated.
    [arm_trunk.urdf]
2026-06-12 Refresh the whole sim around a generated assembly (CAD = source of truth)
    arm_assembly.py is now the single source of truth for the assembled robot: it
    defines the kinematic chain once, DERIVES each joint frame from the build123d
    part geometry, and generates sim/arm_trunk.urdf + the section meshes + a CAD
    preview. The URDF is no longer hand-authored (header says so).
    Refreshed the analysis scripts to the new +X micro-arm geometry:
    - gravity.py: dropped its hand-coded link masses -- they now come from the URDF
    (assembly-derived from part volume + motor estimates).
    - sizing.py: micro cyclo mass, 5mm-blade member cross-section, 150mm sections.
    - backlash.py: lever-arm pose for the +X arm.
    -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
    [arm_trunk.urdf]
2026-06-12 assembly: use the MEASURED 188g full actuator (was ~320g estimate)
    Real measured actuator weight (motor + cyclo) = 188 g. Fold it in, avoiding
    double-counting: the actuator's printed housing/base are already in the section
    mesh, so each section link = blade-only plastic + the 188g actuator (this
    reduces exactly to blade_plastic + ACTUATOR). Link masses drop ~364g -> ~215g;
    the arm is ~40% lighter than the estimate, unloading the shoulder.
    [arm_trunk.urdf]
2026-06-12 Calibrate to measured prototype: 75mm sections, pancake stepper, 1.32 N*m
    Real measurements from the prototype:
    - SEG=75mm (joint-to-joint), pancake stepper actuator (188g, light/weak).
    - Joint torque cap = 1.32 N*m output (1.8kg on a scale at 75mm), where the
    OPEN-LOOP STEPPER misses steps -- the printed cyclo does NOT slip, so it's an
    electrical limit (tunable: more current / closed-loop), not mechanical.
    - Set as the micro joints' effort + gravity.py TAU.
    Sim finding at 75mm + 250g payload, dead-horizontal: shoulder needs 1.42 N*m
    (~8% over the 1.32 cap -> drops steps); elbow 0.77, wrist 0.27 (both fine).
    [arm_trunk.urdf]
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2026-06-13 shoulder_bracket: move bracing to two side gussets (clear the motor face)
    The single central gusset blocked where the shoulder motor mounts. Replace it
    with two gussets at the X edges (GUSSET_W each), bracing the corner while
    leaving the central motor footprint + shaft bore clear.
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2026-06-13 assembly: wrist is the right-angle linkage (angle_drive), 5-DOF
    Per the design: stay 5-DOF (no forearm-roll / double-90). The wrist section is now
    the angle_drive right-angle linkage (cyclo body + NEMA plate) instead of the
    slide-in box -- the wrist-pitch cyclo output carries the tool-roll motor at 90deg.
    Swapped wrist_bracket -> angle_drive in the chain + mesh export; j5 re-placed at
    the NEMA-plate face. (wrist_bracket.py is now unused.)
    [arm_trunk.urdf]
2026-06-13 angle_drive: use the real vendor cyclo mounting plate (NEMA17 + boss)
    Replace the parametric NEMA17 plate with the actual base_nema17 (vendor) -- it
    carries the NEMA17 bolt pattern AND the main bearing boss + bore, the real drive
    geometry. Stood at 90deg to the cyclo body, joined by web + side gussets.
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2026-06-13 watch.py: fix self-triggering reload loop
    Reacting to on_any_event also caught 'opened'/'closed_no_write' events, but
    running the part opens its own .py to read it -- so each run re-triggered the
    watcher forever. Filter to real writes (created/modified/moved) and measure the
    debounce from run END (the build is slow enough that events queued during it
    would otherwise re-fire). Verified: idle = no self-runs, one save = one reload.
2026-06-13 arm_section: heal un-meshable vendor cone faces (NURBS) + BREP cache
    The NEMA17 base's countersink CONE faces import valid but un-triangulable, so
    OCC's mesher skips them -- the chamfers vanish from the OCP viewer and export
    to STL as non-watertight holes. _load() now detects null-triangulation faces and
    NURBS-converts the solid (cones -> splines the mesher handles); housing has none
    so it's untouched. The healed solid is cached as BREP (out/.vendor_cache/,
    gitignored, keyed on the STEP mtime) so the ~1.3s heal is one-time and watch-loop
    rebuilds read the cache (~0.58s).
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2026-06-13 angle_drive: hull web + cap-lip relief + web-only bore clear
    - replace the box riser with a make_hull web (BuildSketch) tapering from the
    body flank up to the plate underside
    - relief pocket so the web clears the drive end-cap lip on top of the body
    (CAP_R = body OD + clearance, on the real body top)
    - clear the body bore out of the WEB ONLY (before unioning the body) so the
    housing's internal cycloidal teeth survive; cut r18.0 to dodge the r18.5
    coincident-face hang
    - tuned GAP/CLEAR/CAP for the current drive
2026-06-13 docs: start LAB_NOTEBOOK.md — process-variable log
    Running notebook for the eventual write-up: a variable catalog (filament brand,
    color/pigment, print orientation, flow cal, elephant's foot; the CAD clearance
    levers; measured-hardware anchors) plus a dated log. First entry: angle_drive
    fits differ from the straight sections — material switch (Bambu -> Elegoo black)
    vs the L-part's two-orthogonal-face orientation conflict.
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2026-06-13 Add angle_mount.py — right-angle joint as two bolt-together flat parts
    Replaces the fused angle_drive approach (which couldn't print every feature
    flat) with two flat-printing pieces that bolt at 90 deg:
    - body_boss(): cyclo body + a boss off its +X side carrying 2 M3 heat-set
    inserts (blind back -> inserts, not nuts). Boss inner face at BORE_R+0.5 so it
    bonds to the body wall only and never reaches the bore/internal teeth.
    - mount_plate(): vendor NEMA17 base + a short flush tab with 2 clearance holes.
    Bearing boss faces outward, flat flange seats flush on the body boss; tab sits
    low to clear it. 9mm thick in X -> prints flat.
    Fasteners spaced horizontally (Y). See LAB_NOTEBOOK.md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
2026-06-14 assembly: motor ladder (38/48/38/24) + 52mm forearm in the sim
    Rework arm_assembly to match the real build's motor plan: per-joint torque caps
    and actuator masses from the NEMA17 ladder (slew 38 / shoulder 48 / elbow 38 /
    wrist 24), output torque anchored to the measured 24mm step-loss (1.32 N*m) and
    scaled by holding torque. Two distinct section meshes: upper arm 75mm (carries
    the 38mm elbow motor), forearm/last-pivot 52mm (carries the 24mm wrist motor).
    Gravity hold @ horizontal: shoulder 1.28/5.5 N*m (4.3x), elbow 0.56/3.6 (6.5x),
    wrist-pitch 0.20/1.32 (6.5x), slew/roll ~0 (their axes carry no gravity). The
    ladder holds the 2.45kg arm + 0.25kg payload with margin everywhere.
    (Geometry m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
    [arm_trunk.urdf]
2026-06-14 assembly: render the real modular parts (cyclo_cage base + angle_mount wrist)
    Swap the cosmetic stand-ins for the actual CAD: base_link is now the cyclo_cage
    (slew drive, feet on the ground), and the wrist is angle_mount -- body_boss +
    mount_plate combined into one wrist_assembly() solid that moves with J4. The sim
    visual now matches the build (kinematics/dynamics already did). Wrist/tool fine
    placement carried over from angle_drive and may want a small tune.
    [arm_trunk.urdf]
2026-06-14 Prune obsolete parts; keep only the current set
    Remove the superseded parts and their artifacts: wrist_bracket, motor_cage,
    angle_drive, shoulder_bracket. The current parts are arm_section, angle_mount
    (body_boss + mount_plate = the 90deg connection used at BOTH the base slew and
    the wrist), pivot_link, and cyclo_cage (base slew drive).
    - cyclo_cage no longer imports motor_cage (inlined its leg/foot constants).
    - arm_assembly drops shoulder_bracket; the base mast and the wrist both use the
    angle_mount solid (renamed wrist_assembly -> angle_mount_solid / angle_mount.stl).
    - Makefile + CAD_NOTES references updated.
    [arm_trunk.urdf]
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2026-06-14 assembly: flip the wrist so the body mates the mount-plate boss side
    The wrist angle_mount was presenting the flat NEMA face to the forearm; flip it
    180deg (rpy z+=pi) so the bearing-boss side is the mating surface, matching how
    the parts actually bolt together.
    [arm_trunk.urdf]
2026-06-14 assembly: orient the wrist so the gripper points forward
    Roll-flip the wrist angle_mount (rpy -pi/2) so the body still mates the forearm
    but the mount-plate output (the perpendicular tool-roll axis) faces +X; move j5
    onto that output so the gripper extends forward instead of pointing back.
    [arm_trunk.urdf]
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2026-06-14 Mate-composed assembly + correct face-to-face drive mating
    Rebuild arm_assembly by MATING parts from the vendor geometry instead of typed
    joint origins: each part exposes mate_frames() (PROX/DIST connectors), the chain
    composes them, and the URDF joint origins/axes + the CAD preview are all derived
    from the same mated Locations (verified rpy round-trips exactly).
    Fix the drive mate to match the real hardware (per a photo of the build): a
    drive joins FACE-TO-FACE -- the mount-plate boss-base face (z=6, where the bearing
    boss rises) seats against the body's OPEN bore face, the boss dropping into the
    bore so the body spins on it. The body mate Z points OUT of the open face so it
    receives the b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
    [arm_trunk.urdf]
2026-06-14 Revert assembly to hand-placed version (the mate-composed one was worse)
    The mate-composition rewrite collapsed/interfered; roll arm_assembly + URDF back
    to 4e20e66 which reads as the arm (base->shoulder->elbow->wrist->gripper). The
    parts' mate_frames() stay (harmless, unused) as foundation if revisited. Next:
    fix the remaining joint mating gaps surgically against the build photo.
    [arm_trunk.urdf]
